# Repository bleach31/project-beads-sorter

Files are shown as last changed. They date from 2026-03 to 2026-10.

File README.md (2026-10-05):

# Project Beads Sorter


📖 [ドキュメント](https://bleach31.github.io/project-beads-sorter/)

ビーズを自動仕分けするシステムのプロジェクトです。  
ソフトウェア（画像認識・制御）と3Dプリント用CADデータを含みます。

## プロジェクト構成

```
project-beads-sorter/
├── impl/                     # 実装成果物
│   ├── src/                  # ソースコード
│   │   └── beads_sorter/     # Pythonパッケージ（Raspberry Pi上で動作）
│   │       ├── vision/       # ビーズ色認識
│   │       └── ejector/      # 仕分け（排出）機構制御
│   ├── cad/                  # 3Dプリント用CADデータ
│   │   ├── parts/            # 個別パーツ
│   │   ├── assembly/         # アセンブリデータ
│   │   └── exports/          # エクスポート済み STL/STEP
│   └── hardware/             # 回路図・配線図
├── tests/                    # テストコード
└── docs/                     # ドキュメント（Sphinx + sphinx-needs）
```

## セットアップ

```bash
# 依存パッケージのインストール（uv が .venv を自動作成）
uv sync

# 開発用パッケージも含めてインストール
uv sync --group dev

# ドキュメント用パッケージも含めてインストール
uv sync --group docs
```

## ドキュメント

```bash
uv run sphinx-build docs docs/_build/html
```

生成されたドキュメントは `docs/_build/html/index.html` で閲覧できます。

## ライセンス

TBD

## Web UI

Pi Camera、ステッピングモーター、押し出しサーボを接続したRaspberry Piで起動する。
サーボ用ハードウェアPWMの設定は
[GPIO19でサーボを制御する](https://bleach31.github.io/project-beads-sorter/servo_pwm.html)
を参照する。

```bash
sudo apt update
sudo apt install -y python3-picamera2

rm -rf .venv
uv venv --system-site-packages
uv sync

sudo .venv/bin/beads-sorter
```

同じネットワークの端末から ``http://<Raspberry PiのIPアドレス>:8000`` にアクセスする。
Web UIでは次の操作ができる。

- ビーズ領域全体から得た平均RGB値と認識色を常時確認
- 色認識、排出先への移動、押し出し、90度への復帰を一括実行
- スロット移動、押し出し、原点設定を個別実行
- 実際のビーズを使った10色の基準色および排出スロットの個別校正
- 認識色ごとの基準RGB、RGB判定範囲、排出スロットの一覧確認
- 独立した設定枠でのステッパー可動量・速度とサーボ角度・待ち時間の調整

ステッパーは柱を横切らない有限ストロークとして制御する。手動で機構をSLOT 0の
位置に合わせて「現在位置を原点に」を押し、「SLOT 0→9 可動量」を終端までの
フルステップ数に設定する。負数を指定すると回転方向が反転する。2相励磁の
フルステップ駆動を使用し、既定値は1536ステップ。以前のハーフステップ設定値を
使う場合は値を半分にしてから、実機の終端位置に合わせて再調整する。

SG90の既定位置は待機90度、押し出し175度。設定値は「校正・機構設定」から実機に
合わせて変更できる。

色は広い探索領域からビーズ表面を抽出し、その領域全体の平均RGBで判定する。
認識結果は常時更新するが、押し出し開始からプッシャーが90度へ戻るまでは直前の
認識結果を保持する。復帰完了後の新しいカメラフレームから自動更新を再開する。
色判定には校正した基準RGBと画面に表示されるチャンネル別のRGB閾値を使用する。

GPIOを接続せず画面とAPIだけを確認する場合はシミュレーションモードで起動する。

```bash
BEADS_SORTER_SIMULATION=1 uv run beads-sorter
```

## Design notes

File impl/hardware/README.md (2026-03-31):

# Hardware

回路図・配線図・BOM（部品表）などの電子回路関連ドキュメントを格納します。

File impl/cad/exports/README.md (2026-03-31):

# CAD Exports

エクスポート済みの STL/STEP ファイルを格納します。  
3Dプリンタへ直接送れる状態のファイルを置きます。

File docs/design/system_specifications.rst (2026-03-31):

システム仕様（v1）
============

認識
----

.. spec:: カメラ色識別
   :id: SPEC_001
   :status: open
   :tags: vision
   :links: REQ_001, REQ_002

   Pi Cameraでビーズの色を識別する。

フィーダー機構
--------------

.. spec:: フィーダー機構
   :id: SPEC_002
   :status: open
   :tags: feeder
   :links: REQ_004

   DCモーター＋ロート型ケース＋テフロンチューブでビーズを供給する。
   DCモーターでロート内をかき混ぜ、ビーズが自重でチューブに入る方式。

排出・仕分け機構
----------------

.. spec:: 排出機構
   :id: SPEC_003
   :status: open
   :tags: ejector
   :links: REQ_001

   サーボモーター（SG90）でビーズを押出/落下排出する。

.. spec:: 回転テーブル仕分け
   :id: SPEC_004
   :status: open
   :tags: ejector
   :links: REQ_001, REQ_002

   ステッピングモーターで回転テーブルを制御し、排出先を10色分切り替える。

制御
----

.. spec:: Raspberry Pi制御
   :id: SPEC_005
   :status: open
   :tags: software
   :links: REQ_001

   Raspberry Pi上のPythonアプリで全体制御する。

筐体
-----

.. spec:: 3Dプリント筐体設計
   :id: SPEC_006
   :status: open
   :tags: mechanical
   :links: REQ_005

   FreeCAD等で設計し、3Dプリントで製作する。

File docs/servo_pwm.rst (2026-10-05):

GPIO19でサーボを制御する
===========================

Raspberry Pi 4のハードウェアPWMを使い、PythonライブラリなしでSG90を制御する。
GPIO19は物理ピン35にあり、PWM1を出力できる。

配線
----

.. list-table::
   :header-rows: 1
   :widths: 30 30 40

   * - SG90
     - 接続先
     - 備考
   * - 信号線
     - GPIO19（物理ピン35）
     - 3.3 VのPWM信号
   * - 電源線
     - 外部5 V電源
     - Raspberry PiのGPIOから給電しない
   * - GND線
     - 外部電源とRaspberry PiのGND
     - 両方のGNDを共通にする

.. warning::

   サーボの電源をRaspberry PiのGPIOから取ると、電圧降下による急な動作や
   Raspberry Piの再起動が発生することがある。十分な電流を供給できる外部5 V
   電源を使用すること。

ハードウェアPWMを有効にする
-----------------------------

アナログ音声はPWM0とPWM1を使用するため無効にする。
``/boot/firmware/config.txt`` にGPIO19のPWMオーバーレイを追加し、再起動する。

.. code-block:: console

   $ sudo sed -i 's/^dtparam=audio=on$/dtparam=audio=off/' /boot/firmware/config.txt
   $ grep -qxF 'dtoverlay=pwm,pin=19,func=2' /boot/firmware/config.txt \
       || echo 'dtoverlay=pwm,pin=19,func=2' \
       | sudo tee -a /boot/firmware/config.txt
   $ sudo reboot

再起動後、GPIO19が ``a5`` （Alt5）になっていることと、PWMデバイスが存在する
ことを確認する。

.. code-block:: console

   $ pinctrl get 19
   19: a5    pd | lo // GPIO19 = PWM1_CHAN1
   $ ls /sys/class/pwm/pwmchip*

サーボを指定角度へ動かす
------------------------

周期を20 ms（50 Hz）に設定し、PWM出力を開始する。以下は90度の例である。
数値の単位はナノ秒。

.. code-block:: console

PWMCHIP=$(find /sys/class/pwm -maxdepth 1 -name 'pwmchip*' -print -quit)
test -n "$PWMCHIP" || { echo 'PWM device not found' >&2; exit 1; }
test -d "$PWMCHIP/pwm1" || echo 1 | sudo tee "$PWMCHIP/export"
echo 20000000 | sudo tee "$PWMCHIP/pwm1/period"
echo 1400000 | sudo tee "$PWMCHIP/pwm1/duty_cycle"
echo 1 | sudo tee "$PWMCHIP/pwm1/enable"

PWMはコマンド終了後も出力されるため、サーボは指定角度を保持する。

角度を変更する
--------------

0度から180度までの角度を指定する。パルス幅は0度で0.5 ms、90度で1.4 ms、
180度で2.3 msとなる。

.. code-block:: console

   $ ANGLE=90
   $ test "$ANGLE" -ge 0 -a "$ANGLE" -le 180 \
       || { echo 'ANGLE must be between 0 and 180' >&2; exit 1; }
   $ echo $((500000 + ANGLE * 10000)) \
       | sudo tee "$PWMCHIP/pwm1/duty_cycle"

サーボによって可動範囲には差がある。端で振動したり機構に当たったりする場合は、
0度および180度付近を避けて安全な範囲に調整する。

PWMを停止する
-------------

次のコマンドでPWMを停止し、サーボを解放する。

.. code-block:: console

   $ echo 0 | sudo tee "$PWMCHIP/pwm1/enable"

停止後にサーボが負荷で動くのは、保持トルクがなくなるためである。
PWM出力中に勢いよく別の角度へ動く場合は、外部5 V電源の容量、GNDの共通接続、
信号線の接触、および別プロセスからのGPIO操作を確認する。

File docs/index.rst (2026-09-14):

.. Beads Sorter documentation master file.

Beads Sorter ドキュメント
=========================

ビーズを自動仕分けするシステムのドキュメントです。
ソフトウェア（画像認識・制御）と3Dプリント用CADデータを含みます。

.. toctree::
   :maxdepth: 2
   :caption: 目次:

   requirements/system_requirements
   design/index
   servo_pwm
   shopping_list
   wbs_v1

Indices and tables
==================

* :ref:`genindex`
* :ref:`modindex`
* :ref:`search`

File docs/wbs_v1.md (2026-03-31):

# WBS v1 — ビーズ仕分け機

## 1. 設計

- [ ] **1.1 全体アーキテクチャ設計** — ソフト・ハード・CAD間の接続・通信方式を決定する
- [ ] **1.2 フィーダー機構設計** — ロート+スクリュー+テフロンチューブの形状・寸法を検討する（SPEC_002）
- [ ] **1.3 認識部設計** — Pi Cameraの取付位置・照明条件を決定する（SPEC_001）
- [ ] **1.4 排出・ターンテーブル機構設計** — サーボ排出+回転テーブルの配置・寸法を検討する（SPEC_003, SPEC_004）
- [ ] **1.5 回路設計** — モータードライバ・電源配線・ラズパイGPIO割当を決定する

## 2. 部品調達

- [ ] **2.1 電子部品購入** — ステッピングモーター、サーボ、DCモーター、Pi Camera、ケーブル類
- [ ] **2.2 ビーズ素材購入** — アイロンビーズセット、アクアビーズセット（テスト用）
- [ ] **2.3 3Dプリント準備** — フィラメント確認、プリンタ利用可否確認

## 3. CAD・3Dプリント

- [ ] **3.1 フィーダー部パーツ** — ロート・スクリュー・チューブ取付部の設計・印刷
- [ ] **3.2 認識部パーツ** — カメラ固定マウント・照明カバーの設計・印刷
- [ ] **3.3 排出・ターンテーブル部パーツ** — サーボ固定・ターンテーブル本体・仕切りの設計・印刷
- [ ] **3.4 本体フレーム** — 全機構を組み付けるベースフレームの設計・印刷
- [ ] **3.5 組立・フィッティング確認** — 全パーツ組み付け、干渉チェック

## 4. 回路・配線

- [ ] **4.1 モータードライバ回路** — ステッピングモーター・DCモーター用ドライバ回路を製作
- [ ] **4.2 Raspberry Pi配線** — GPIO接続・カメラ接続・電源接続
- [ ] **4.3 電源配線** — Type-C電源取り出し・各モーターへの給電

## 5. ソフトウェア開発

- [ ] **5.1 カメラ画像取得・色認識** — Pi Cameraで撮影→色判定ロジック実装（vision モジュール）
- [ ] **5.2 サーボモーター制御** — SG90の角度制御・ビーズ排出動作実装（ejector モジュール）
- [ ] **5.3 ステッピングモーター制御** — 28BYJ-48のターンテーブル回転制御実装（ejector モジュール）
- [ ] **5.4 DCモーター制御** — フィーダーのかき混ぜ動作制御実装
- [ ] **5.5 全体制御フロー統合** — 供給→認識→仕分け→排出の一連動作を統合

## 6. テスト・調整

- [ ] **6.1 フィーダー動作テスト** — ビーズが1個ずつ安定供給されるか検証・調整（最重要）
- [ ] **6.2 色認識精度テスト** — 10色の識別精度を検証・閾値調整
- [ ] **6.3 排出・仕分け精度テスト** — ターンテーブル位置精度・排出成功率を検証
- [ ] **6.4 統合テスト** — 10色ビーズの連続仕分け動作を確認

## 7. ドキュメント

- [ ] **7.1 組立手順書** — 筐体組立・配線手順のドキュメント作成
- [ ] **7.2 ソフトウェアドキュメント** — Sphinx自動生成ドキュメントの整備

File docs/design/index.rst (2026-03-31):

設計ドキュメント
================

.. toctree::
   :maxdepth: 2

   system_specifications

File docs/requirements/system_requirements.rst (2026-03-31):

システム要件
============

.. req:: 自動仕分け
   :id: REQ_001
   :status: open
   :tags: system

   ビーズを色ごとに自動仕分けできること。

.. req:: 仕分け色数
   :id: REQ_002
   :status: open
   :tags: system

   10色を識別・仕分けできること。

.. req:: 対象ビーズ
   :id: REQ_003
   :status: open
   :tags: system

   アイロンビーズ（φ5mm×h5mm）およびアクアビーズ まるビーズに対応すること。

.. req:: ビーズ供給
   :id: REQ_004
   :status: open
   :tags: feeder

   ビーズを1個ずつ供給できること。

.. req:: 3Dプリント筐体
   :id: REQ_005
   :status: open
   :tags: mechanical

   筐体は3Dプリントで製作可能であること。

.. req:: Type-C給電
   :id: REQ_006
   :status: open
   :tags: electrical

   電源はType-C給電を前提とすること。

.. req:: 段階的改善
   :id: REQ_007
   :status: open
   :tags: system

   3台製作し段階的に改善すること（v1→v2→v3）。

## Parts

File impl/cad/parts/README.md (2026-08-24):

# CAD Parts

個別の3Dプリント用パーツデータを格納します。

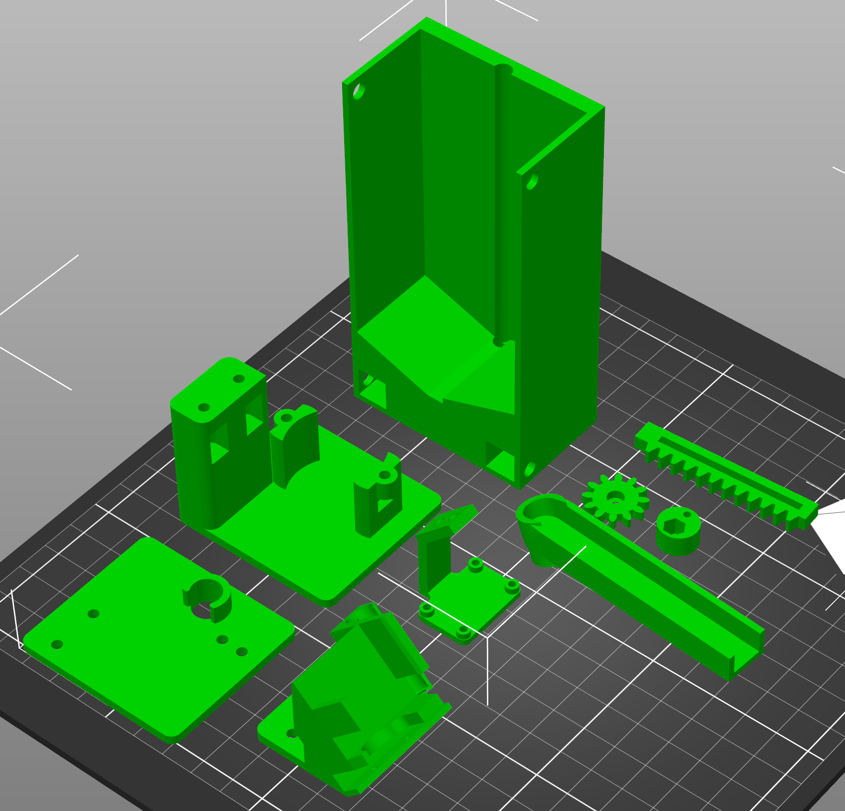
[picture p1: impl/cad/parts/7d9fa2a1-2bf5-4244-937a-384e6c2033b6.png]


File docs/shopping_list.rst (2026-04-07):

購入リスト
==========

ビーズ素材（すぐ買う）
----------------------

.. list-table::
   :header-rows: 1
   :widths: 40 10 5 10 35

   * - 品名
     - 単価
     - 数量
     - 小計
     - リンク
   * - カワダ ナノビーズ 48色セット（80-54359）
     - 2,000円
     - 1
     - 2,000円
     - `Amazon <https://amzn.asia/d/0aaS77dO>`_
   * - カワダ パーラービーズ はじめてのパーラービーズ（80-53562）
     - 2,500円
     - 2
     - 5,000円
     - `ヨドバシ <https://www.yodobashi.com/product/100000001008967962/>`_
   * - アクアビーズ 24色ビーズセット
     - 2,000円
     - 1
     - 2,000円
     - `Amazon <https://amzn.asia/d/0eiE7y9v>`_
   * - アクアビーズ オールインワンセット AQ-S100
     - 2,200円
     - 2
     - 4,400円
     - `Amazon <https://amzn.asia/d/05Ghk8zT>`_

電子部品・配線（すぐ買う）
--------------------------

.. list-table::
   :header-rows: 1
   :widths: 30 10 5 10 20 25

   * - 品名
     - 単価
     - 数量
     - 小計
     - 備考
     - リンク
   * - Pi カメラ
     - 3,680円
     - 1
     - 3,680円
     - —
     - `Amazon <https://amzn.asia/d/04VM8zAc>`_
   * - テフロンチューブ 内径6mm 外径8mm
     - TBD
     - TBD
     - TBD
     - —
     - `Monotaro <https://www.monotaro.com/p/2256/4185/>`_
   * - ジャンパーワイヤーセット
     - TBD
     - 1
     - TBD
     - —
     - `Amazon <https://amzn.asia/d/01w6icpt>`_
   * - ブレッドボードセット
     - TBD
     - 1
     - TBD
     - —
     - `Amazon <https://amzn.asia/d/02CD9BOB>`_
   * - USB電源（2口）
     - TBD
     - 1
     - TBD
     - —
     - `Amazon <https://amzn.asia/d/0g5OZgwS>`_
   * - USB A-Aケーブル
     - TBD
     - 1
     - TBD
     - ステッピングモーター電源用
     - `Amazon <https://amzn.asia/d/0hr6xmwm>`_
   * - ラズパイ USB-シリアルケーブル
     - TBD
     - 1
     - TBD
     - —
     - `Amazon <https://amzn.asia/d/03HLOSte>`_

電子部品（後日）
----------------

.. list-table::
   :header-rows: 1
   :widths: 30 10 5 10 20 25

   * - 品名
     - 単価
     - 数量
     - 小計
     - 備考
     - リンク
   * - LCDディスプレイ（カラー）
     - TBD
     - 3
     - TBD
     - —
     - —
   * - Raspberry Pi 4 Model B / 4GB
     - 15,290円
     - 3
     - 45,870円
     - —
     - `スイッチサイエンス <https://www.switch-science.com/products/5680>`_
   * - Type-C電源（ラズパイ用）
     - TBD
     - 3
     - TBD
     - —
     - —
   * - Type-C電源（モーター用）
     - TBD
     - 3
     - TBD
     - —
     - —
   * - Type-C 電圧取り出しボード
     - TBD
     - 3
     - TBD
     - —
     - —

持込・共用品
------------

.. list-table::
   :header-rows: 1
   :widths: 50 50

   * - 品名
     - 提供元
   * - Raspberry Pi 3
     - メンバー提供（確認中）
   * - サーボモーター SG90（押し出し用）
     - メンバー提供
   * - ステッピングモーター 28BYJ-48 + 電源ボード（首振り用）
     - メンバー提供
   * - DCモーター（フィーダー用）
     - メンバー提供
   * - microUSBケーブル（ラズパイ電源用）
     - メンバー提供
   * - フィラメント（3Dプリンタ用）
     - 共用品

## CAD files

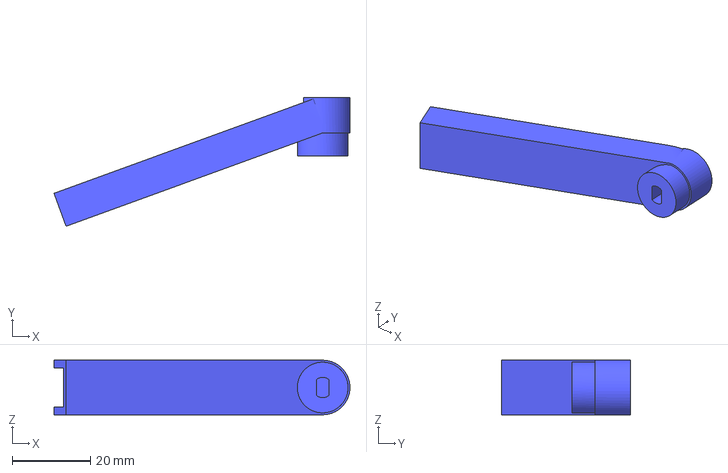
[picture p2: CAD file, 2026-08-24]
impl/cad/parts/nozzle.3mf
75.9 x 33.0 x 14.0 mm

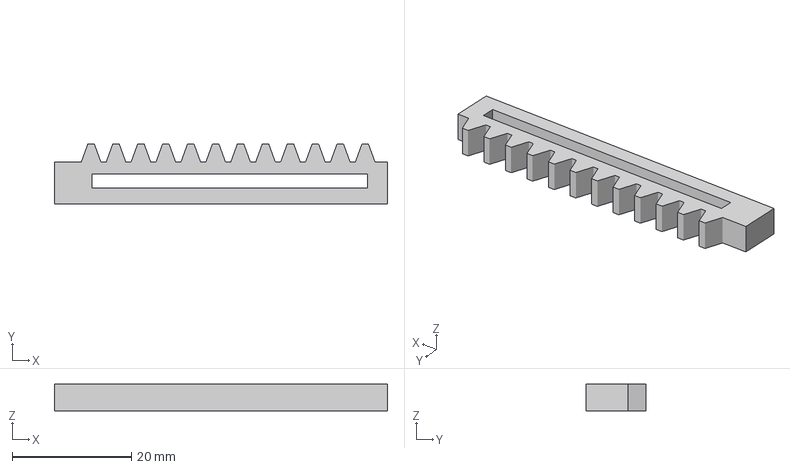
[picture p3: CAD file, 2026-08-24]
impl/cad/parts/rack.3mf
55.9 x 10.00 x 4.50 mm

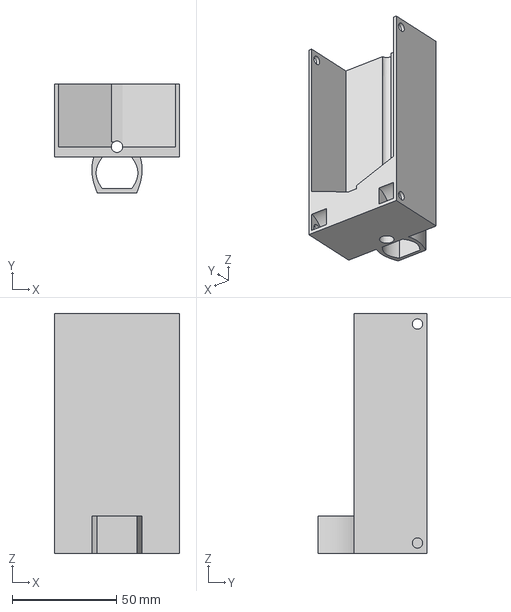
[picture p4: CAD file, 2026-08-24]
impl/cad/parts/feeder2v2.3mf
60.0 x 52.1 x 115.0 mm

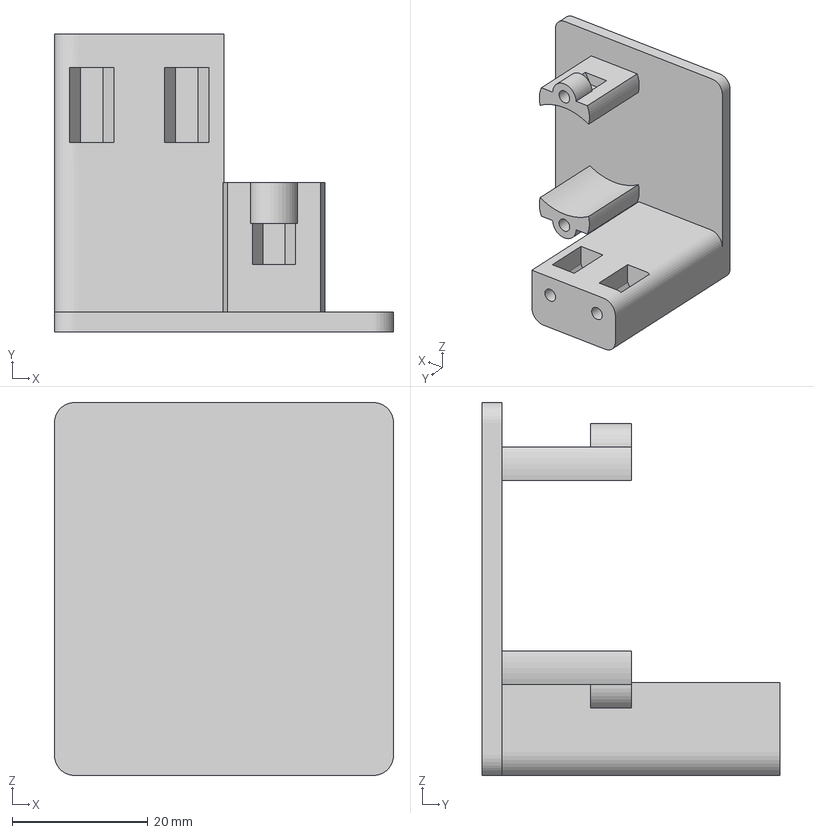
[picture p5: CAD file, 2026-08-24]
impl/cad/parts/low-base.3mf
50.0 x 44.0 x 55.0 mm

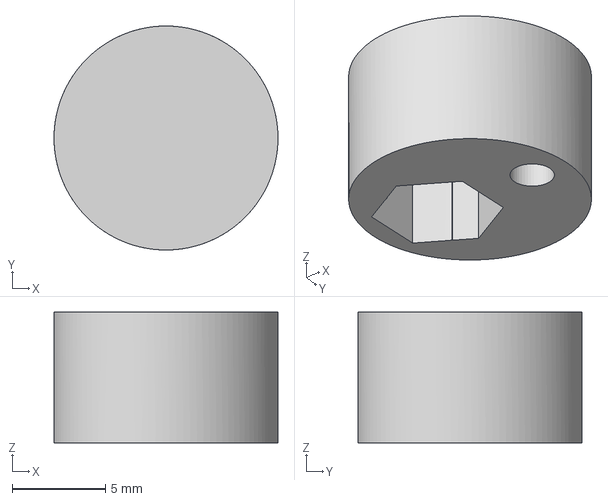
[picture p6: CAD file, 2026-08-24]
impl/cad/parts/eccentric-weight.3mf
12.0 x 12.0 x 7.00 mm

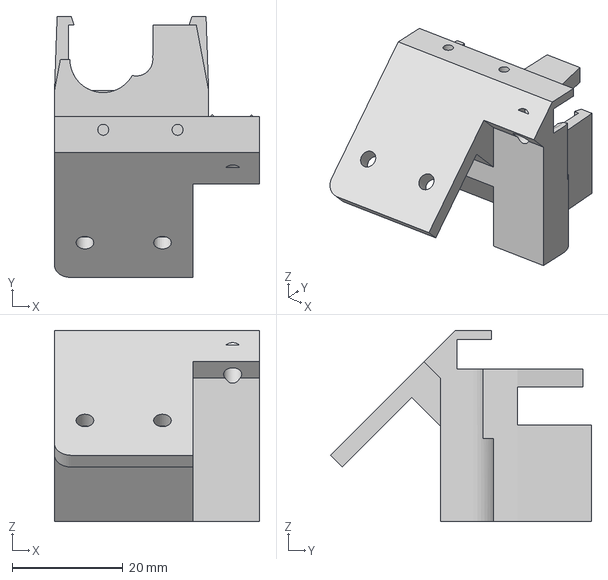
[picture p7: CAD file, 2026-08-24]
impl/cad/parts/upper-base.3mf
37.0 x 47.1 x 34.6 mm

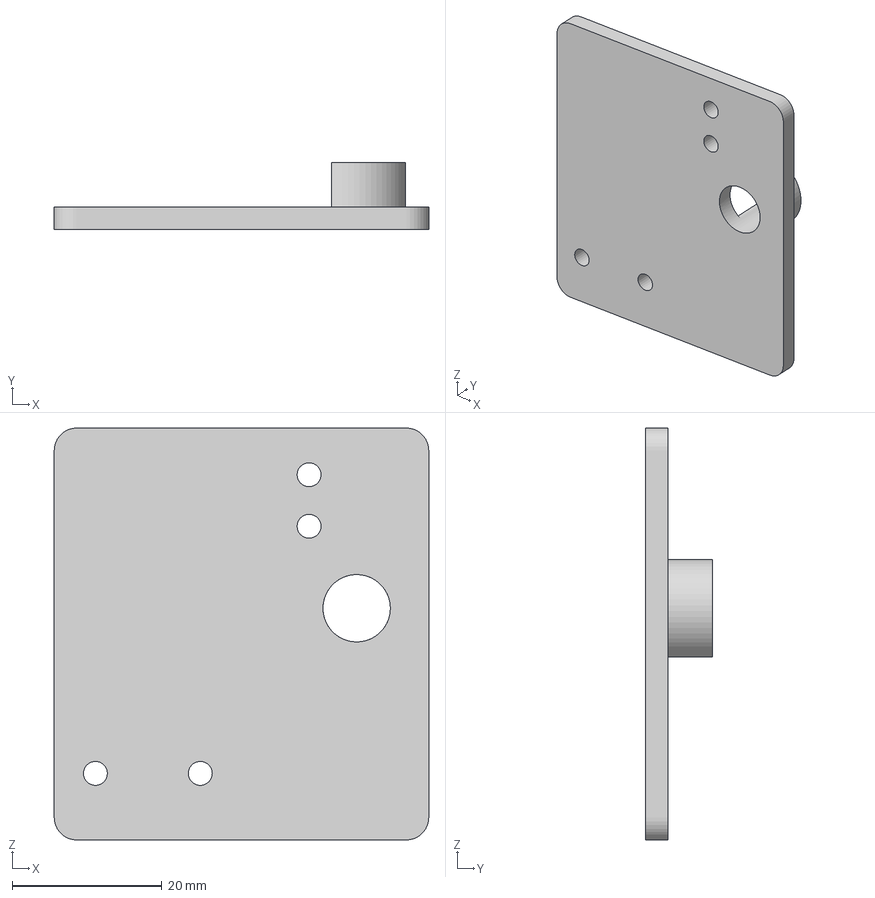
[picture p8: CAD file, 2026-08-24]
impl/cad/parts/middle-base.3mf
50.0 x 9.00 x 55.0 mm

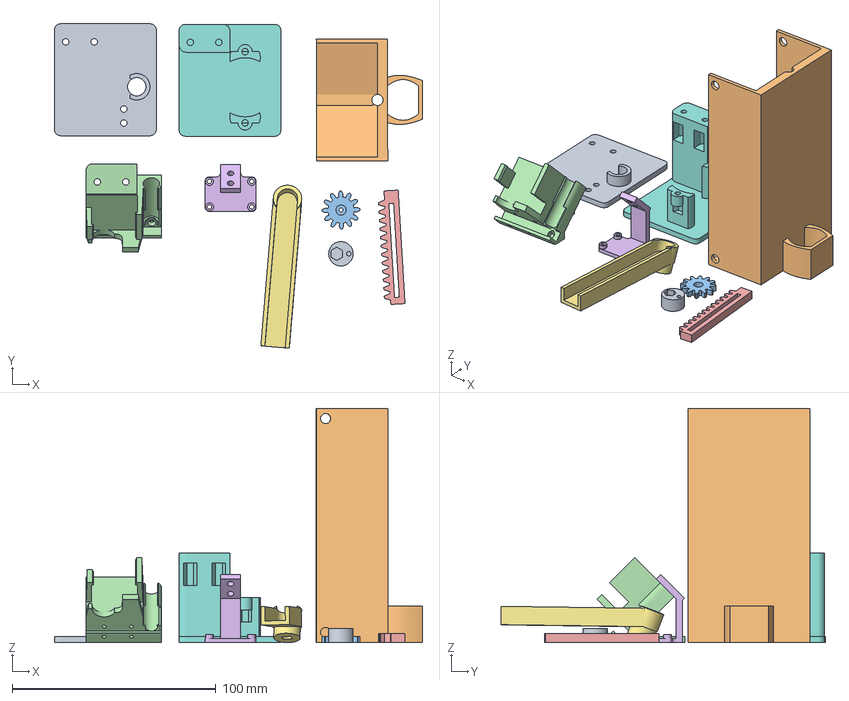
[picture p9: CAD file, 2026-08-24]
impl/cad/parts/pinion.3mf
180.7 x 159.3 x 115.0 mm
eccentric-weight
feeder2v2
pinion
upper-base
rack
camera-mount
nozzle
low-base
middle-base

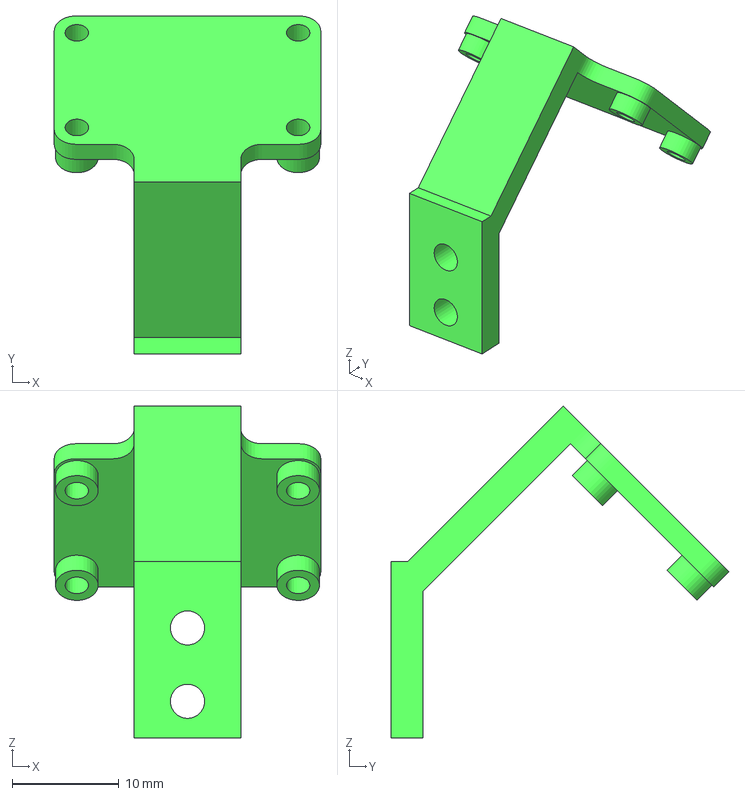
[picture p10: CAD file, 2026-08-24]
impl/cad/parts/camera-mount.3mf
25.0 x 31.7 x 31.1 mm

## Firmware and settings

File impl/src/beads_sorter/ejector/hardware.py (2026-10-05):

"""Hardware drivers for the sorting table and bead pusher."""

import time
from collections.abc import Callable
from pathlib import Path
from threading import Lock
from typing import Protocol


class HardwareUnavailableError(RuntimeError):
    """Raised when the configured Raspberry Pi hardware cannot be used."""


class DigitalOutput(Protocol):
    value: int

    def close(self) -> None: ...


FULL_STEP_SEQUENCE = (
    (1, 1, 0, 0),
    (0, 1, 1, 0),
    (0, 0, 1, 1),
    (1, 0, 0, 1),
)


def _gpio_output(pin_number: int) -> DigitalOutput:
    try:
        from gpiozero import OutputDevice
    except ImportError as error:
        raise HardwareUnavailableError(
            "gpiozero is required to control the stepper motor"
        ) from error
    return OutputDevice(pin_number, initial_value=False)


class StepperMotor:
    """Drive a 28BYJ-48 in full-step mode and track the table position."""

    def __init__(
        self,
        pins: tuple[int, int, int, int] = (17, 18, 27, 22),
        *,
        travel_steps: int = 1536,
        slot_count: int = 10,
        step_delay: float = 0.004,
        pin_factory: Callable[[int], DigitalOutput] = _gpio_output,
        sleep: Callable[[float], None] = time.sleep,
    ) -> None:
        if travel_steps == 0 or slot_count < 2 or step_delay < 0:
            raise ValueError("Stepper travel must be non-zero and slots at least two")
        self.travel_steps = travel_steps
        self.slot_count = slot_count
        self.step_delay = step_delay
        self._sleep = sleep
        self._pins = tuple(pin_factory(pin) for pin in pins)
        self._position_steps = 0
        self._lock = Lock()

    @property
    def current_slot(self) -> int:
        slot = round(
            self._position_steps * (self.slot_count - 1) / self.travel_steps
        )
        return min(max(slot, 0), self.slot_count - 1)

    def set_home(self) -> None:
        """Mark the current physical table position as slot zero."""
        with self._lock:
            self._position_steps = 0

    def configure(self, *, travel_steps: int, step_delay: float) -> None:
        """Apply motion tuning while preserving the current logical slot."""
        if travel_steps == 0 or step_delay < 0:
            raise ValueError("Stepper travel must be non-zero")
        with self._lock:
            slot = self.current_slot
            self.travel_steps = travel_steps
            self.step_delay = step_delay
            self._position_steps = round(
                slot * self.travel_steps / (self.slot_count - 1)
            )

    def move_to_slot(self, slot: int) -> int:
        """Move within the configured bounded travel and return signed steps."""
        if not 0 <= slot < self.slot_count:
            raise ValueError(f"slot must be between 0 and {self.slot_count - 1}")

        with self._lock:
            target = round(slot * self.travel_steps / (self.slot_count - 1))
            steps = target - self._position_steps
            self._move_steps(steps)
            self._position_steps = target
            return steps

    def _move_steps(self, steps: int) -> None:
        sequence = FULL_STEP_SEQUENCE if steps >= 0 else tuple(
            reversed(FULL_STEP_SEQUENCE)
        )
        try:
            for step in range(abs(steps)):
                self._set_outputs(sequence[step % len(sequence)])
                self._sleep(self.step_delay)
        finally:
            self.release()

    def _set_outputs(self, pattern: tuple[int, int, int, int]) -> None:
        for pin, value in zip(self._pins, pattern):
            pin.value = value

    def release(self) -> None:
        self._set_outputs((0, 0, 0, 0))

    def close(self) -> None:
        with self._lock:
            self.release()
            for pin in self._pins:
                pin.close()


class SysfsServo:
    """Control an SG90 through the Raspberry Pi hardware PWM sysfs API."""

    def __init__(
        self,
        *,
        channel: int = 1,
        push_angle: int = 175,
        rest_angle: int = 90,
        hold_seconds: float = 0.35,
        settle_seconds: float = 0.35,
        pwm_root: Path = Path("/sys/class/pwm"),
        sleep: Callable[[float], None] = time.sleep,
    ) -> None:
        if not 0 <= push_angle <= 180 or not 0 <= rest_angle <= 180:
            raise ValueError("Servo angles must be between 0 and 180")
        self.channel = channel
        self.push_angle = push_angle
        self.rest_angle = rest_angle
        self.hold_seconds = hold_seconds
        self.settle_seconds = settle_seconds
        self.pwm_root = pwm_root
        self._sleep = sleep
        self._pwm_path: Path | None = None
        self._lock = Lock()

    @staticmethod
    def _angle_to_duty_cycle(angle: int) -> int:
        return 500_000 + angle * 10_000

    def _find_pwm_chip(self) -> Path:
        for chip in sorted(self.pwm_root.glob("pwmchip*")):
            try:
                if int((chip / "npwm").read_text().strip()) > self.channel:
                    return chip
            except (OSError, ValueError):
                continue
        raise HardwareUnavailableError(
            f"No PWM chip with channel {self.channel} found under {self.pwm_root}"
        )

    def _ensure_pwm(self) -> Path:
        if self._pwm_path is not None:
            return self._pwm_path

        chip = self._find_pwm_chip()
        pwm_path = chip / f"pwm{self.channel}"
        if not pwm_path.exists():
            (chip / "export").write_text(str(self.channel))
            for _ in range(100):
                if pwm_path.exists():
                    break
                self._sleep(0.01)
        if not pwm_path.exists():
            raise HardwareUnavailableError(f"PWM channel did not appear at {pwm_path}")

        enable_path = pwm_path / "enable"
        if enable_path.read_text().strip() == "1":
            enable_path.write_text("0")
        (pwm_path / "period").write_text("20000000")
        self._pwm_path = pwm_path
        return pwm_path

    def _set_angle(self, angle: int) -> None:
        pwm_path = self._ensure_pwm()
        (pwm_path / "duty_cycle").write_text(
            str(self._angle_to_duty_cycle(angle))
        )
        if (pwm_path / "enable").read_text().strip() != "1":
            (pwm_path / "enable").write_text("1")

    def push_and_return(self) -> None:
        """Push one bead, return to rest, and release the servo."""
        with self._lock:
            self._set_angle(self.push_angle)
            try:
                self._sleep(self.hold_seconds)
            finally:
                self._set_angle(self.rest_angle)
                self._sleep(self.settle_seconds)
                if self._pwm_path is not None:
                    (self._pwm_path / "enable").write_text("0")
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

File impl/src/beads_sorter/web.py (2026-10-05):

"""FastAPI operator interface for the bead sorter."""

import asyncio
import os
from contextlib import asynccontextmanager
from dataclasses import asdict
from threading import Lock
from typing import Any, Callable

from fastapi import FastAPI, HTTPException
from fastapi.responses import HTMLResponse, StreamingResponse
from pydantic import BaseModel, Field

from beads_sorter.controller import SortController
from beads_sorter.ejector.hardware import (
    HardwareUnavailableError,
    StepperMotor,
    SysfsServo,
)
from beads_sorter.vision.camera import CameraService, CameraUnavailableError
from beads_sorter.vision.color import ColorClassifier, ColorMatch

COLOR_LABELS = {
    "red": "赤",
    "orange": "オレンジ",
    "yellow": "黄",
    "green": "緑",
    "cyan": "水色",
    "blue": "青",
    "purple": "紫",
    "pink": "ピンク",
    "white": "白",
    "black": "黒",
    "unknown": "判定外",
}


class BusyError(RuntimeError):
    """Raised when another mechanical operation is already active."""


class UnavailableStepper:
    def __init__(self, error: str) -> None:
        self.error = error
        self.current_slot = 0
        self.travel_steps = 1536
        self.step_delay = 0.004

    def _raise(self) -> None:
        raise HardwareUnavailableError(self.error)

    def move_to_slot(self, slot: int) -> int:
        self._raise()
        return 0

    def set_home(self) -> None:
        self._raise()

    def configure(self, **_values: Any) -> None:
        self._raise()

    def close(self) -> None:
        pass


class SimulatedStepper:
    def __init__(self) -> None:
        self.current_slot = 0
        self.travel_steps = 1536
        self.step_delay = 0.004

    def move_to_slot(self, slot: int) -> int:
        old_position = round(self.current_slot * self.travel_steps / 9)
        new_position = round(slot * self.travel_steps / 9)
        steps = new_position - old_position
        self.current_slot = slot
        return steps

    def set_home(self) -> None:
        self.current_slot = 0

    def configure(self, *, travel_steps: int, step_delay: float) -> None:
        if travel_steps == 0:
            raise ValueError("Stepper travel must be non-zero")
        self.travel_steps = travel_steps
        self.step_delay = step_delay

    def close(self) -> None:
        pass


class SimulatedPusher:
    def __init__(self) -> None:
        self.push_angle = 175
        self.rest_angle = 90
        self.hold_seconds = 0.35
        self.settle_seconds = 0.35

    def push_and_return(self) -> None:
        pass

    def configure(self, **values: Any) -> None:
        for name, value in values.items():
            setattr(self, name, value)

    def close(self) -> None:
        pass


class AppRuntime:
    """Own application services and observable operation state."""

    def __init__(
        self,
        camera: Any | None = None,
        stepper: Any | None = None,
        pusher: Any | None = None,
        *,
        simulation: bool | None = None,
    ) -> None:
        self.camera = camera or CameraService()
        requested_simulation = simulation
        if requested_simulation is None:
            requested_simulation = os.getenv("BEADS_SORTER_SIMULATION") == "1"

        self.hardware_error: str | None = None
        if stepper is not None:
            self.stepper = stepper
            self.hardware_mode = "injected"
        elif requested_simulation:
            self.stepper = SimulatedStepper()
            self.hardware_mode = "simulation"
        else:
            try:
                self.stepper = StepperMotor()
                self.hardware_mode = "gpio"
            except Exception as error:
                self.hardware_error = str(error)
                self.stepper = UnavailableStepper(str(error))
                self.hardware_mode = "unavailable"

        if pusher is not None:
            self.pusher = pusher
        elif requested_simulation:
            self.pusher = SimulatedPusher()
        else:
            self.pusher = SysfsServo()

        classifier = ColorClassifier()
        slots = {name: slot for slot, name in enumerate(classifier.references)}
        self.controller = SortController(classifier, self.stepper, self.pusher, slots)
        self._operation_lock = Lock()
        self._state_lock = Lock()
        self.busy = False
        self.action = "idle"
        self.last_error: str | None = None
        self.last_result: dict[str, Any] | None = None
        self.last_detection: ColorMatch | None = None
        self._recognition_paused = False

    def start(self) -> None:
        self.camera.start()

    def close(self) -> None:
        self.camera.stop()
        self.stepper.close()
        self.pusher.close()

    def execute(self, action: str, operation: Callable[[], Any]) -> Any:
        if not self._operation_lock.acquire(blocking=False):
            raise BusyError("Another mechanical operation is running")
        with self._state_lock:
            self.busy = True
            self.action = action
            self.last_error = None
        try:
            result = operation()
            if hasattr(result, "__dataclass_fields__"):
                self.last_result = asdict(result)
            return result
        except Exception as error:
            with self._state_lock:
                self.last_error = str(error)
            raise
        finally:
            with self._state_lock:
                self.busy = False
                self.action = "idle"
            self._operation_lock.release()

    def recognize_current(
        self,
        *,
        after_sequence: int | None = None,
    ) -> ColorMatch:
        reading = self.camera.get_reading(after_sequence=after_sequence)
        match = self.controller.recognize(reading.rgb)
        with self._state_lock:
            self.last_detection = match
        return match

    def _refresh_live_detection(self) -> ColorMatch | None:
        reading = self.camera.latest()
        if reading is None:
            return None
        with self._state_lock:
            if self._recognition_paused:
                return self.last_detection
            self.last_detection = self.controller.recognize(reading.rgb)
            return self.last_detection

    def _push_with_recognition_paused(self) -> ColorMatch:
        with self._state_lock:
            self._recognition_paused = True
        try:
            self.pusher.push_and_return()
            latest = self.camera.latest()
            after_sequence = latest.sequence if latest is not None else None
            reading = self.camera.get_reading(after_sequence=after_sequence)
            match = self.controller.recognize(reading.rgb)
            with self._state_lock:
                self.last_detection = match
            return match
        finally:
            with self._state_lock:
                self._recognition_paused = False
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

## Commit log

2026-04-07 remove cad documentation and update index references; add shopping list
2026-08-24 CADパーツデータを追加: 3MF形式の新しいファイルを追加
    [camera-mount.3mf, eccentric-weight.3mf, feeder2v2.3mf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]
2026-09-14 add servo control and stepper motor test scripts
2026-09-14 document GPIO19 hardware PWM servo control
2026-10-05 feat: refine recognition and calibration controls
2026-11-09 cadパーツをメンテ
2026-11-10 add 5mm extended slope
2026-11-13 feat(cad): add v10 bases with 4.8 mm push rod guides
